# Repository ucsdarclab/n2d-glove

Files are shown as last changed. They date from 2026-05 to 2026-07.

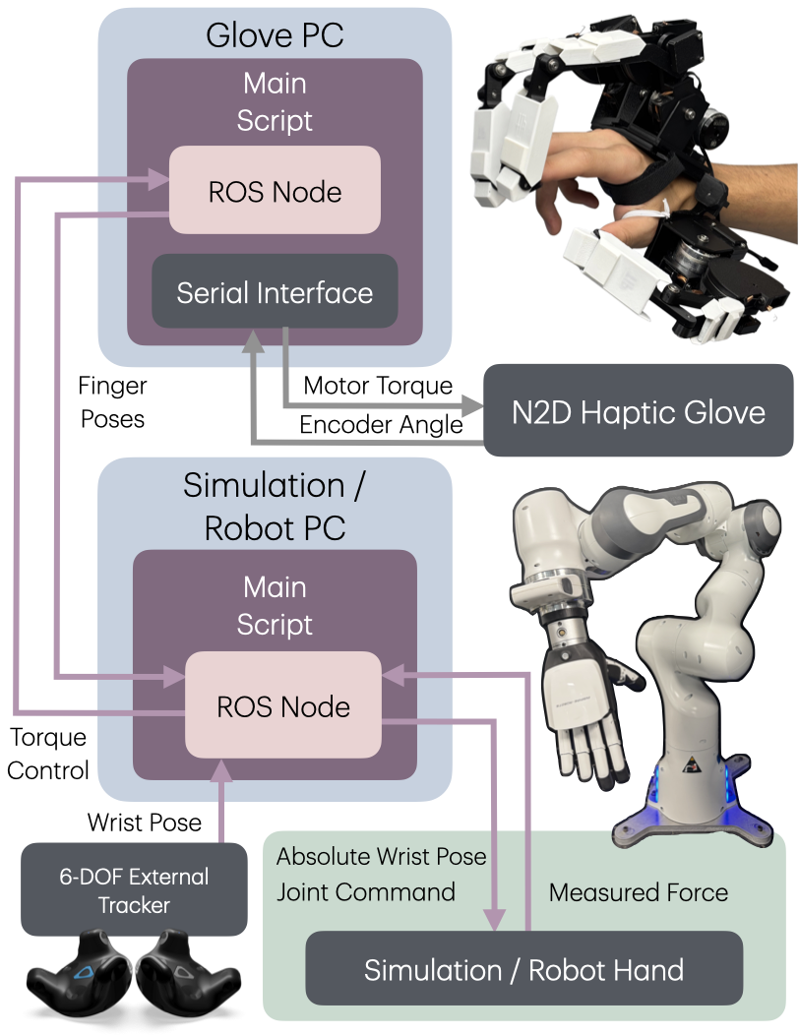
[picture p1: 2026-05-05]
website/src/assets/fig3_architecture.png

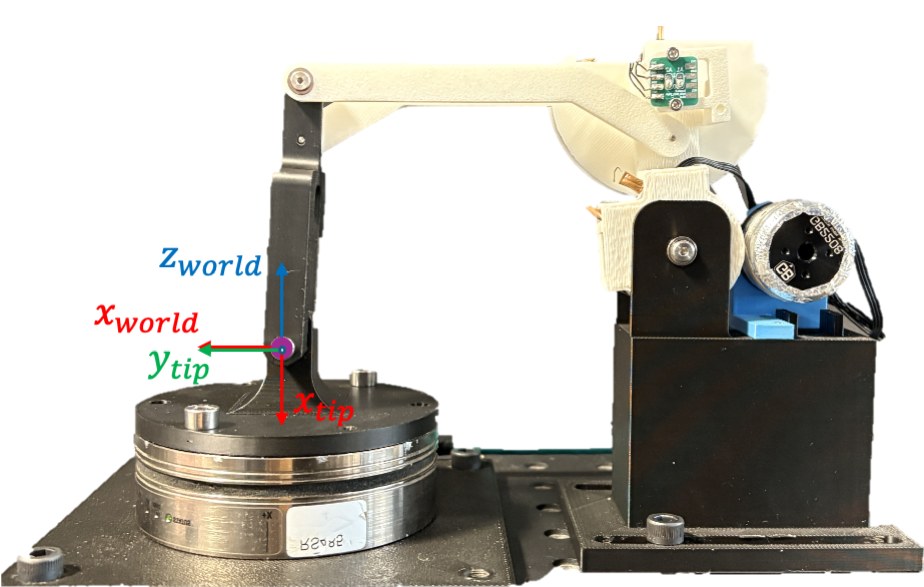
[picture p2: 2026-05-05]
website/src/assets/fig5_calibration.jpg

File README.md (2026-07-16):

# n2d-glove

- `website/` - Project Website at [ucsdarclab.github.io/n2d-glove/](https://ucsdarclab.github.io/n2d-glove/)
- `PCBs/` - PCB Files
- `STLs/` - Ready-to-print STL files for right-hand glove. All files pre-duplicated for easy printing.

## Parts List (As of 07/11/2026)

[Google Sheet](https://docs.google.com/spreadsheets/d/1Ua4gmWuUEBylOtv7NlKw2PqBZjRJq9b11pPJc5YkHVY/edit?usp=sharing)

| Part | Easy Buy Link | Link | Quantity | Unit Price | Total Price | Description |
| --- | --- | --- | --- | --- | --- | --- |
| GB2208 | No | https://store.tmotor.com/goods.php?id=447 | 6 | $25.90 | $155.40 | 2 motors per finger x 3 fingers (6 required). |
| Main PCB (CompactN2D) | No | https://github.com/ucsdarclab/n2d-glove/raw/refs/heads/main/PCBs/CompactN2D%20Gerbers.zip | 1 | $10 | $10 | Large PCB with Teensy 4.1 and 6x Driver Boards |
| Encoder PCB (ARCLab miniAS5048B) | No | https://github.com/ucsdarclab/n2d-glove/raw/refs/heads/main/PCBs/ARCLab_miniAS5048B_Gerbers.zip | 10 | $1 | $10 | Small PCB for mounting encoder. 3 per finger plus 1 thumb |
| AS5048B encoder IC (AS5048B-HTSP) | DigiKey Cart Share | https://www.digikey.com/en/products/detail/ams-osram-usa-inc/AS5048B-HTSP/3188635 | 10 | $6.46 | $64.60 | 12-bit magnetic angle encoder with programmable I2C address |
| 4-pin encoder cable | https://www.digikey.com/short/v38wvwd3 | https://www.digikey.com/en/products/detail/molex/2263921043/23571260 | 3 | $3.10 | $9.30 | One per finger |
| 4-pin encoder connector | ^ | https://www.digikey.com/en/products/detail/molex/2147210040/16115264 | 3 | $1.26 | $3.78 | One per finger |
| 100nF 0603 capacitor (CL10B104JB8NNNC) | ^ | https://www.digikey.com/en/products/detail/samsung-electro-mechanics/CL10B104JB8NNNC/3886691 | 10 | $0.04 | $0.40 | One per encoder PCB |
| 10uF 0603 capacitor (CL10A106KP8NNNC) | ^ | https://www.digikey.com/en/products/detail/samsung-electro-mechanics/CL10A106KP8NNNC/3886850 | 10 | $0.10 | $1.00 | One per encoder PCB |
| Teensy 4.1 without Ethernet (SparkFun 20359) | ^ | https://www.digikey.com/en/products/detail/sparkfun-electronics/20359/16688101 | 1 | $29.60 | $29.60 | Main PCB Microcontroller |
| 3.5mm Screw Terminal (GCT TAD05-02-1-L-G) | ^ | https://www.digikey.com/en/products/detail/gct/TAD05-02-1-L-G/26408919 | 1 | $0.41 | $0.41 | Main PCB Power Input |
| 4-conductor 28 AWG ribbon cable (Adafruit 3891) | ^ | https://www.digikey.com/en/products/detail/adafruit-industries-llc/3891/9603617 | 1 | $1.95 | $1.95 | Extra wire for connecting encoders |
| Shoulder screw 3x8mm (90318A416) | McMaster Cart Share | https://www.mcmaster.com/90318A416/ | 12 | $3.66 | $43.92 | 12 required. M2 x 0.4 threaded tip |
| Shoulder screw 4x12mm (90323A216) | https://www.mcmaster.com/order/rcvRtedOrd.aspx?ordid=4762453288527&lnktyp=txt | https://www.mcmaster.com/90323A216/ | 4 | $4.13 | $16.52 | 4 required. M3 x 0.5 tip |
| Shoulder screw 4x30mm (90323A443) | ^ | https://www.mcmaster.com/90323A443/ | 3 | $10.52 | $31.56 | 3 required, 1 per front GB2208 motor. M3 x 0.5 tip |
| Shim 1/8"ID x 3/16"OD x 0.005" (99040A305) | ^ | https://www.mcmaster.com/99040A305/ | 2 pack (25) | $14.06/pack | $28.12 | 24 required. Slips over 3mm shoulder screws. Fragile recommend extra |
| Shim 3/16"ID x 1/4"OD x 0.005" (99040A405) | ^ | https://www.mcmaster.com/99040A405/ | 1 pack (25) | $14.06/pack | $14.06 | 14 required. Slips over 4mm shoulder screws |
| M3x8 flat head screw (92125A128) | ^ | https://www.mcmaster.com/92125A128/ | 1 pack (100) | $7.08/pack | $7.08 | 18 required. For motor mounts and plate mounts |
| M3 thin hex nut, stainless (90710A030) | ^ | https://www.mcmaster.com/90710A030/ | 1 pack (100) | $13.52/pack | $13.52 | 3 required, on 4x30 bolt tip at front motor |
| M2 hex nut (90591A265) | ^ | https://www.mcmaster.com/90591A265/ | 1 pack (100) | $2.22/pack | $2.22 | 6 required, capstan wire tensioners. |
| M2 washer (93475A195) | ^ | https://www.mcmaster.com/93475A195/ | 1 pack (100) | $2.92/pack | $2.92 | 6 required, under tensioner nuts. |
| M2x20 socket head screw (91290A049) | ^ | https://www.mcmaster.com/91290A049/ | 1 pack (100) | $16.58/pack | $16.58 | 6 required, capstan wire tension screws. |
| M2.5x5 button head screw (92095A457) | ^ | https://www.mcmaster.com/92095A457/ | 1 pack (25) | $4.42/pack | $4.42 | Encoder holder screws, 2 per encoder (20 required) |
| Diametric magnet 3/16"x1/16" (5862K412) | ^ | https://www.mcmaster.com/5862K412/ | 10 | $1.33 | $13.30 | One per encoder. N52, must be diametric |
| Capstan drive wire rope 7x19 (3461T192) | ^ | https://www.mcmaster.com/3461T192/ | 1 (10 ft) | $18.37 | $18.37 | 18-8 SS extra-flexible, 0.018" dia. |
| Copper Wire Rope Stop Sleeve, 1/32" (McMaster 3926T42) | ^ | https://www.mcmaster.com/3926T42/ | 1 pack (50) | $9.47/pack | $9.47 | Crimps to terminate capstan wire |
| SimpleFOC Mini Driver Board | No | https://www.aliexpress.us/w/wholesale-simplefoc-mini.html | 6 | $5.74 | $34.44 | 6 for 6 motors |
| Heat-set insert kit M2 + M2.5 + M3 (Ktehloy 400pc) | No | https://www.amazon.com/dp/B0CLKDPN65 | 1 kit (400pc) | $14.98 | $14.98 | Encoder mounts, thumb CMC joint. etc. |
| MF63ZZ flanged bearing 3x6x2.5mm | No | https://www.amazon.com/dp/B0F4XS52R6 | 20+10 (30) | $9.49 + $8.19 | $17.68 | 24 required, ~8/finger |
| MF74ZZ flanged bearing 4x7x2.5mm | No | https://www.amazon.com/dp/B0F4XPW7YB | 1 pack (20) | $8.49/pack | $8.49 | 14 required, ~5/finger |
| 1/2in x 100ft Hook and Loop Roll | No | https://www.amazon.com/dp/B0CH8K8VWC | 1 | $7.99 | $7.99 | Velcro for palm attachment, ~1ft needed |
| Graphite Dry Lock Lubricant Powder, 4.5g | No | https://www.amazon.com/dp/B00YRZUGH6 | 1 | $5.15 | $5.15 | Lubricant for smoother abduction/adduction |
| Elastic Bracelet String, 2 Rolls (1.5mm) | No | https://www.amazon.com/dp/B0CBTRGHJN | 1 | $7.99 | $7.99 | Elastic cord for thumb attachment, ~0.5ft needed |
| Total Price |  |  |  |  | $605.22 |  |

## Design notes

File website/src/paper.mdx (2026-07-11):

---
title: "The N2D Haptic Glove"
subtitle: "A Multi-Finger Glove for 2D Directional Force Feedback for Contact-Rich Manipulation"
authors:
  - name: Yao-Ting Huang
    notes: ["†", "1"]
  - name: Jake Honma
    notes: ["†", "2"]
  - name: Omar Hernandez
    notes: ["†", "1"]
  - name: Logan Li
    notes: ["†", "3"]
  - name: Kaitlin Calimbahin
    notes: ["†", "1"]
  - name: Bryce Hackel
    notes: ["1"]
  - name: Michael C. Yip
    notes: ["1"]
    institution: Senior Member, IEEE
notes:
  - symbol: "†"
    text: " Equal contribution."
  - symbol: "1"
    text: " Electrical and Computer Engineering, University of California San Diego, La Jolla, CA 92093, USA."
  - symbol: "2"
    text: " Mechanical and Aerospace Engineering, University of California San Diego, La Jolla, CA 92093, USA."
  - symbol: "3"
    text: " Bioengineering, University of California San Diego, La Jolla, CA 92093, USA."
links:
  - name: Paper
    url: "https://arxiv.org/pdf/2606.14083"
    icon: ri:file-pdf-2-line
  - name: Code
    url: "https://github.com/ucsdarclab/n2d-glove"
    icon: ri:github-line
  - name: arXiv
    url: "https://arxiv.org/abs/2606.14083"
    icon: academicons:arxiv

theme: device
favicon: favicon.svg

description: A wearable multi-finger haptic glove that renders 2D planar directional force feedback at the fingertips for contact-rich teleoperation, VR, and imitation learning.
thumbnail: og-thumbnail.jpg
---

import Video from "./components/Video.astro";
import HighlightedSection from "./components/HighlightedSection.astro";
import Figure from "./components/Figure.astro";
import Picture from "./components/Picture.astro";
import TwoColumns from "./components/TwoColumns.astro";
import Wide from "./components/Wide.astro";

import fig1Hero from "./assets/fig1_hero.jpg";
import fig2Linkage from "./assets/fig2_linkage.png";
import fig3Architecture from "./assets/fig3_architecture.png";
import fig4Kinematics from "./assets/fig4_kinematics.png";
import fig5Calibration from "./assets/fig5_calibration.jpg";
import fig5Tracking from "./assets/fig5_tracking.png";
import fig6Workspace from "./assets/fig6_workspace.jpg";
import fig7Franka from "./assets/fig7_franka.jpg";
import fig8Boxplots from "./assets/fig8_boxplots.png";
import fig9Tlx from "./assets/fig9_tlx.png";

<Figure>
  <Picture slot="figure" src={fig1Hero} alt="The N2D Haptic Glove worn on a hand" />
  <Fragment slot="caption">**The N2D Haptic Glove** — the first multi-fingered glove design that offers 2D force feedback along the axial direction of multiple fingers, enabling probing, gentle grasping, and slip detection.</Fragment>
</Figure>

<HighlightedSection>

## Abstract

Humans rely on directional fingertip forces to probe and regulate contact during manipulation, yet most wearable haptic gloves render only vibration or single-axis force, leaving force direction ambiguous. Without directional cues, users must infer contact force from vision alone, often leading to over-pressing, inconsistent control, and reduced precision in robotic teleoperation. We present the **N2D Haptic Glove**, a multi-finger wearable device that renders planar flexion–extension fingertip forces using capstan-drive transmissions for high-transparency force feedback. Through benchtop validations and a user study involving haptic teleoperation of a robotic arm and hand, we demonstrate that compared to visual-only and single-axis baselines, planar fingertip feedback significantly reduces contact force error during precise manipulation, improves trial-to-trial consistency, and enhances overall user experience in axial probing tasks.

</HighlightedSection>

## Contributions

1. The **first** multi-fingered haptic glove capable of delivering planar force feedback to the fingertip.
2. A mechanical design that achieves high transparency through low-friction, zero-backlash transmissions for clean, accurate haptic rendering.
3. Validation of 2D planar directional feedback ability with benchtop testing.
4. A teleoperation user study demonstrating the benefits of N2D's directional haptics over no-haptic and 1D-haptic baselines.

## Hardware Design

The N2D Haptic Glove is designed to preserve the natural biomechanical DOFs of the hand. The MCP joint is treated as a saddle joint allowing flexion–extension and adduction–abduction; PIP and DIP joints are modeled as revolute joints constrained to flexion–extension. The thumb additionally performs opposition at the TMC joint. The thumb, index, and middle fingers — central to most grasping and probing tasks — are actuated.

The device consists of three modular finger subsystems mounted along a structural backbone. Each subsystem uses a crossed four-bar linkage with an additional link to permit full flexion–extension while enabling 2D planar force feedback. Planar fingertip forces are generated by actuating the proximal links via capstan cable drives. Each linkage is mounted on a passive rotary joint for finger abduction–adduction, with the thumb having an additional passive joint for TMC opposition.

All active DOFs are driven by **GB2208 gimbal motors** through capstan transmissions, avoiding geared transmissions that introduce backlash, friction, and damping. Actuators are mechanically grounded at the base of the linkage, preventing motor masses from rotating about the finger joints. The total glove weighs **562 g** (battery off-hand).

<Figure>
  <Picture slot="figure" src={fig2Linkage} alt="Deconstructed view of the N2D Haptic Glove finger linkage" />
  <Fragment slot="caption">Deconstructed view of the N2D Haptic Glove showing finger linkage joint layout and its correspondence to hand anatomy.</Fragment>
</Figure>

### Comparison to Existing Fingertip-Feedback Systems

| System | Multi-DOF Forces | Kinesthetic | Multi-Digit |
| :--- | :---: | :---: | :---: |
| SenseGlove R1 | ✗ | ✓ | ✓ |
| HaptGlove | ✗ | ✓ | ✓ |
| DOGlove | ✗ | ✓ | ✓ |
| NURing | ✓ | ✓ | ✗ |
| Fluid Reality | ✗ | ✗ | ✓ |
| AirPush | ✓ | ✗ | ✗ |
| **N2D Glove (ours)** | **✓** | **✓** | **✓** |

## System Architecture

The Glove PC computes finger poses from encoder data and sends joint commands to the Simulation/Robot PC via ROS. Each motor–encoder pair interfaces with a Teensy 4.1 microcontroller running field-oriented control in torque mode at **1 kHz**, while higher-level torque commands stream from the Glove PC at **10 Hz** over a serial connection. An external **VIVE Tracker 3.0** provides absolute wrist pose, fused with fingertip pose estimates. Sensed interaction forces are returned through ROS and mapped to motor commands, closing the bilateral control loop.

<Figure>
  <Picture slot="figure" src={fig3Architecture} alt="N2D Haptic Glove system architecture diagram" />
  <Fragment slot="caption">System architecture. The Glove PC computes finger poses from encoder data and sends joint commands to the Simulation/Robot PC via ROS. Sensed interaction forces are returned and mapped to motor commands.</Fragment>
</Figure>

## Kinematic Modeling

<Figure>
  <Picture slot="figure" src={fig4Kinematics} alt="Single finger linkage with three DOFs and labeled coordinate frames" />
  <Fragment slot="caption">Kinematic analysis of a single finger linkage with three DOFs defined by $q_0, q_1, q_2$ ($q_3$ being a driven joint).</Fragment>
</Figure>

Each finger is modeled as a rigid linkage with three revolute joints $q_{f,0}, q_{f,1}, q_{f,2}$ and link lengths $a_{f,0}, a_{f,1}, a_{f,2}, a_{f,3}$. The driven angle $q_{f,3}$ is solved via the cosine law:

$$
CD = \ell_4 = \sqrt{a_2^2 + \ell_5^2 + 2 a_2 \ell_5 \cos q_{f,2}}
$$

Directional haptics are then rendered by mapping Cartesian forces in the world frame, $\mathbf{f}^w_f \in \mathbb{R}^3$, to joint torques $\boldsymbol{\tau}_f \in \mathbb{R}^2$ via the **Jacobian transpose**:

$$
\boldsymbol{\tau}_f = \mathbf{J}^w_f(\mathbf{q}_f)^\top \mathbf{f}^w_f
$$

Because each finger has only two active DOF, the achievable Cartesian forces lie in a configuration-dependent 2D subspace of $\mathbb{R}^3$. The Jacobian-transpose mapping naturally projects any commanded force onto this subspace; the un-actuated direction (finger abduction/adduction) is not reflected.

## Validation Experiments

A voltage–torque mapping is identified per joint via a quasi-static calibration. Circular planar force trajectories were commanded and measured with an ATI Axia80 3-DOF sensor.

- **RMSE_x = 0.032 N**
- **RMSE_z = 0.014 N**
- **RMSE_|e| = 0.034 N**, **RMSE_θ = 2.81°**

The fingertip Jacobian is well-conditioned with $\kappa(\mathbf{J}^w_f) \approx 2.93$, and the manipulability $w(\mathbf{q}_f) \geq 0.82$ over **58%** of sampled configurations — confirming that directional forces can be rendered cleanly across most reachable hand postures.

<Figure>
  <Picture slot="figure" src={fig5Calibration} alt="Force calibration setup with finger linkage mounted on an ATI force sensor" />
  <Fragment slot="caption">Force calibration setup showing the world coordinate frame ($x_{\text{world}}$, $z_{\text{world}}$) and the tip coordinate frame ($x_{\text{tip}}$, $y_{\text{tip}}$).</Fragment>
</Figure>

<Figure>
  <Picture slot="figure" src={fig5Tracking} alt="Force tracking results: commanded vs. measured along x and z axes, and in the x z plane" />
  <Fragment slot="caption">Individual commanded and measured force components along the x and z axes (left), and measured forces in the x–z plane compared to the commanded circular trajectory (right). RMSE: $0.032$ N (x), $0.014$ N (z), $0.034$ N (magnitude), $2.81°$ (angle).</Fragment>
</Figure>

<Figure>
  <Picture slot="figure" src={fig6Workspace} alt="Workspace range-of-motion scatter for small and large hands" />
  <Fragment slot="caption">Workspace range of motion for a small and large hand. The overlaid manipulability indicates configuration-dependent directional force capability, showing well-conditioned force generation throughout typical operating regions.</Fragment>
</Figure>

## Teleoperation User Study

Sixteen participants teleoperated a **Franka Emika Panda** arm with an **Inspire RH56DFTP** dexterous hand to press a digital scale toward target weights of 50 g and 100 g, under three feedback modes: **no haptics**, **1D haptics**, and **full 2D haptics**. Two contact orientations were tested: axial probing (fingertip contact) and transverse probing (finger pad contact).

<Figure>
  <Picture slot="figure" src={fig7Franka} alt="Franka arm and Inspire hand scale-pressing teleoperation setup" />
  <Fragment slot="caption">Teleoperation setup: a Franka arm with an Inspire dexterous hand presses a digital scale toward a target weight under three feedback conditions.</Fragment>
</Figure>

### Results

In **axial probing**, median absolute error decreased progressively from no-haptics → 1D → 2D feedback. At the 100 g target, 2D feedback significantly outperformed both 1D ($p = 0.032$) and no-feedback ($p = 1.43 \times 10^{-5}$) conditions, demonstrating that 2D directional feedback enhances force regulation where single-DOF resistive feedback is insufficient.

| Condition | Mode | Median Abs. Err. (g) | $p$ vs. Vis | $p$ vs. 1D |
| :--- | :--- | :---: | :---: | :---: |
| Axial 50 g | Visual | 37.68 | — | $2.53\!\times\!10^{-4}$ |
| Axial 50 g | 1D | 30.80 | $2.53\!\times\!10^{-4}$ | — |
| Axial 50 g | **2D** | **24.99** | $2.56\!\times\!10^{-6}$ | 0.276 |
| Axial 100 g | Visual | 50.25 | — | 0.032 |
| Axial 100 g | 1D | 34.73 | 0.032 | — |
| Axial 100 g | **2D** | **21.20** | $1.43\!\times\!10^{-5}$ | **0.032** |
| Transverse 50 g | **2D** | **27.85** | $5.07\!\times\!10^{-4}$ | 0.876 |
| Transverse 100 g | **2D** | **46.52** | 0.0315 | 0.985 |

<Figure>
  <Picture slot="figure" src={fig8Boxplots} alt="Boxplots of absolute error for 50 g and 100 g target weights across feedback modalities" />
  <Fragment slot="caption">Boxplots of absolute error (g) for target weights of 50 g and 100 g. In axial probing, median error decreases progressively from visual-only to 1D to 2D feedback.</Fragment>
</Figure>

NASA-TLX surveys show that 2D haptic feedback significantly **reduces cognitive load** and increases **perceived feedback quality** for both axial and transverse probing.

<Figure>
  <Picture slot="figure" src={fig9Tlx} alt="NASA-TLX survey results across feedback modalities" />
  <Fragment slot="caption">Individual NASA-TLX survey results for axial and transverse probing, demonstrating that multi-directional haptic feedback significantly reduces cognitive load while improving overall performance for participants.</Fragment>
</Figure>

## Conclusion

Directional fingertip haptics are essential for realistic physical interaction in teleoperation. The N2D Haptic Glove demonstrates that multi-directional 2D feedback is both feasible and beneficial for contact-rich tasks, particularly those involving axial probing — pushing small buttons, palpation, peg-in-hole insertion, and fingertip-based search in confined environments. The glove provides a foundation for next-generation wearable haptic interfaces supporting more natural and effective human–robot interaction across teleoperation, immersive VR simulation, and imitation learning.

## BibTeX

```bibtex
@misc{n2dglove2026,
  author = "{Authors Redacted}",
  title  = "The N2D Haptic Glove: A Multi-Finger Glove for 2D Directional
            Force Feedback for Contact-Rich Manipulation",
  year   = "2026",
}
```

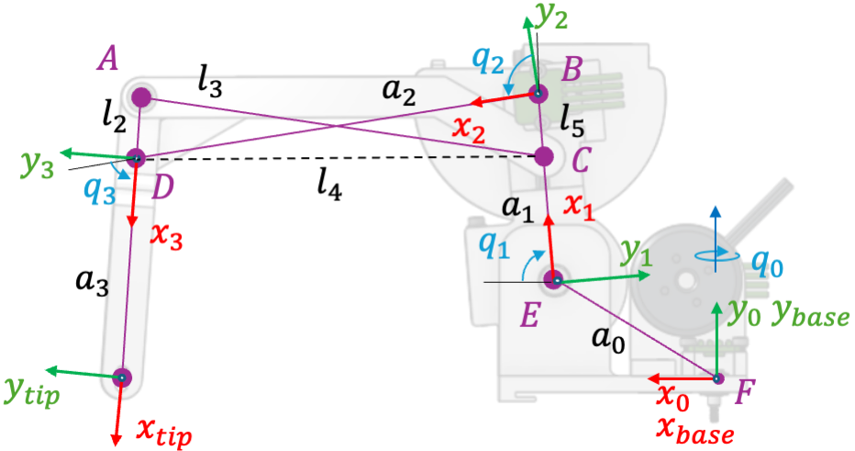
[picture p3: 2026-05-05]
website/src/assets/fig4_kinematics.png

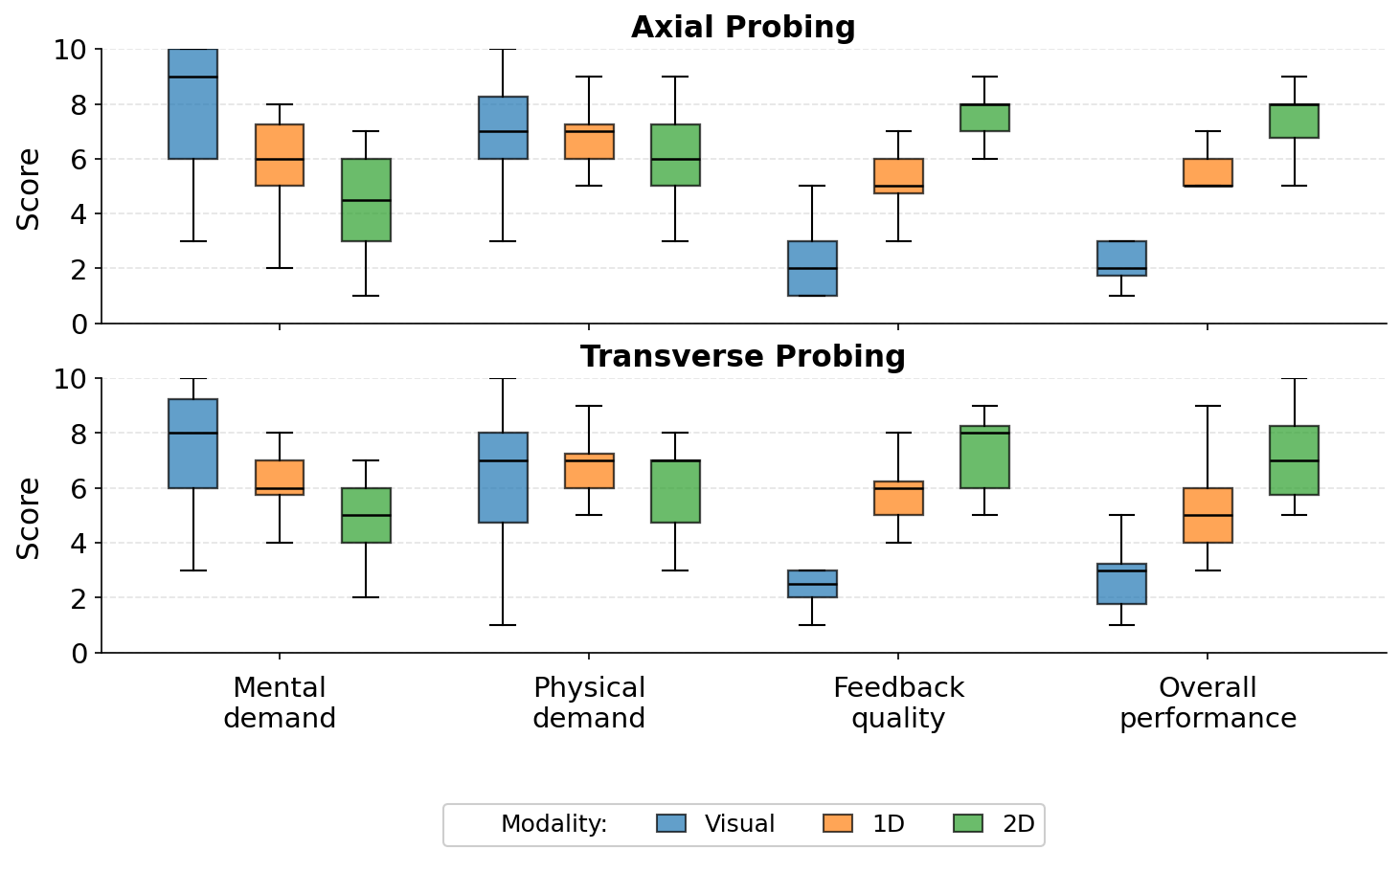
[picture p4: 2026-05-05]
website/src/assets/fig9_tlx.png

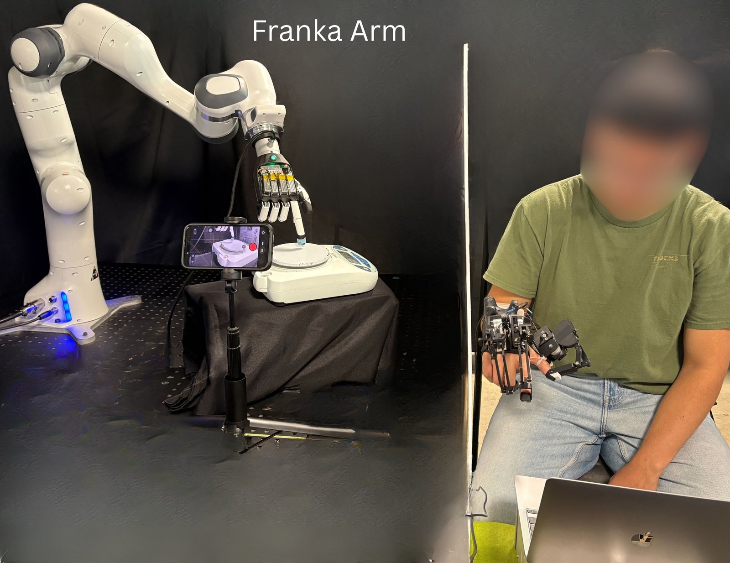
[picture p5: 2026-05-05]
website/src/assets/fig7_franka.jpg

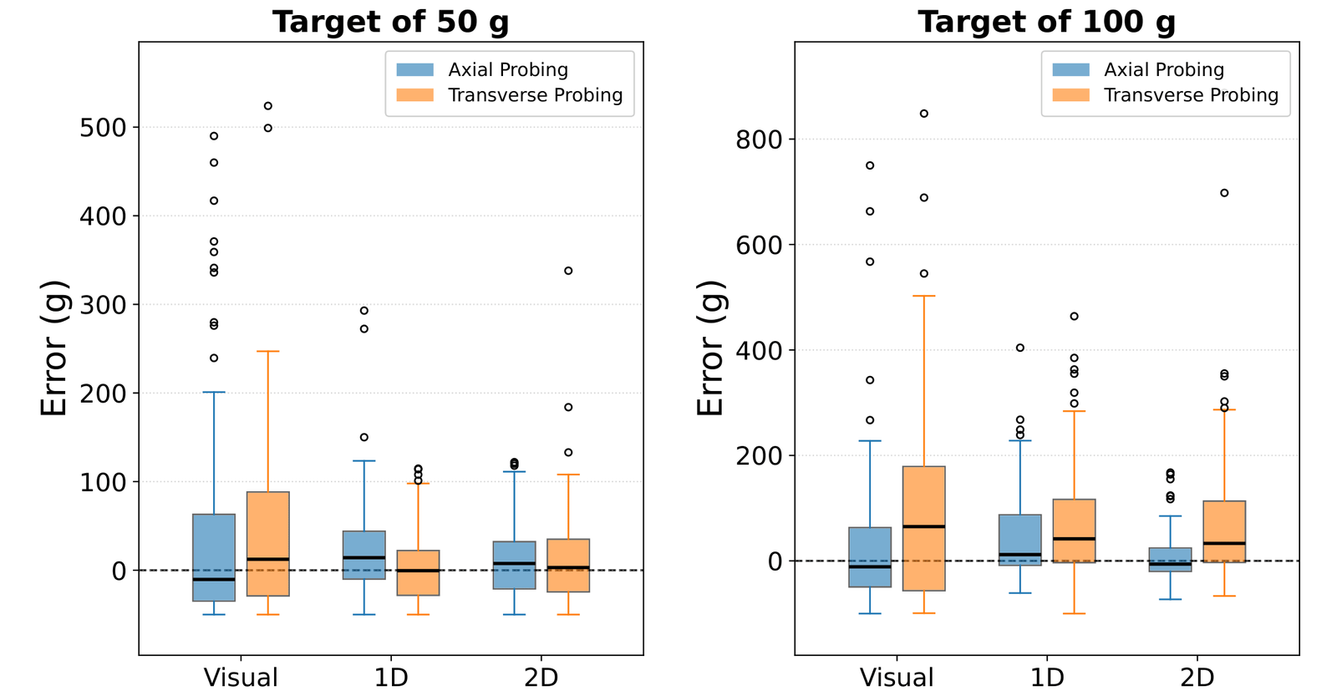
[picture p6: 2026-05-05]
website/src/assets/fig8_boxplots.png

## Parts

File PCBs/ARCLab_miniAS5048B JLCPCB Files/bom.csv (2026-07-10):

Designator | Footprint | Quantity | Value | LCSC Part #
A1, A2 | SolderJumper-3_P1.3mm_Open_RoundedPad1.0x1.5mm | 2 | SolderJumper_3_Open
C1 | 0603 | 1 | 100n | CL10B104KB8NNNC
C2 | 0603 | 1 | 10u | CL10A106MP8NNNC
J1, J2 | 4Pin Wire SolderPad | 2 | Conn_01x04_Pin
U1 | SOP65P640X120-14N | 1 | AS5048B-HTSP-500 | C2655184

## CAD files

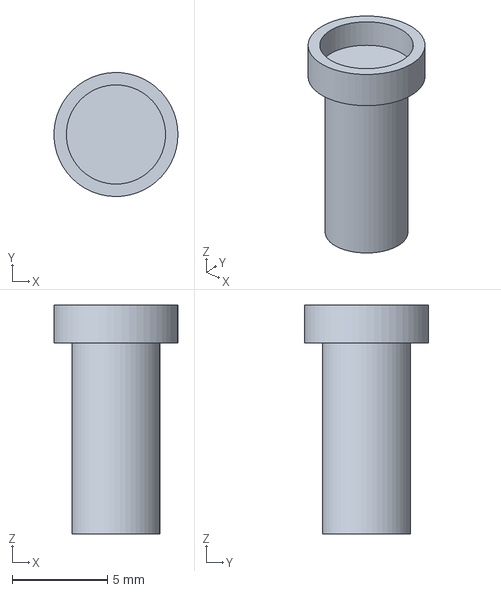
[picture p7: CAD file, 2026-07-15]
STEPs/3 Finger Assembly - Magnet Shaft.step
6.49 x 6.50 x 12.0 mm

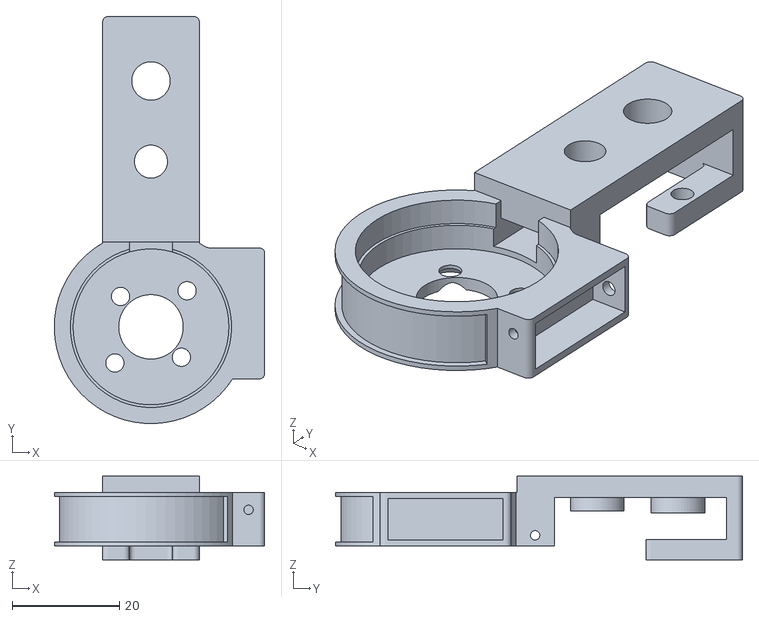
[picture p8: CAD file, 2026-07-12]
STLs/3 Finger Assembly - Capstan Drive Proximal Link Thumb and Pointer (copy 2).stl
39.2 x 75.7 x 15.5

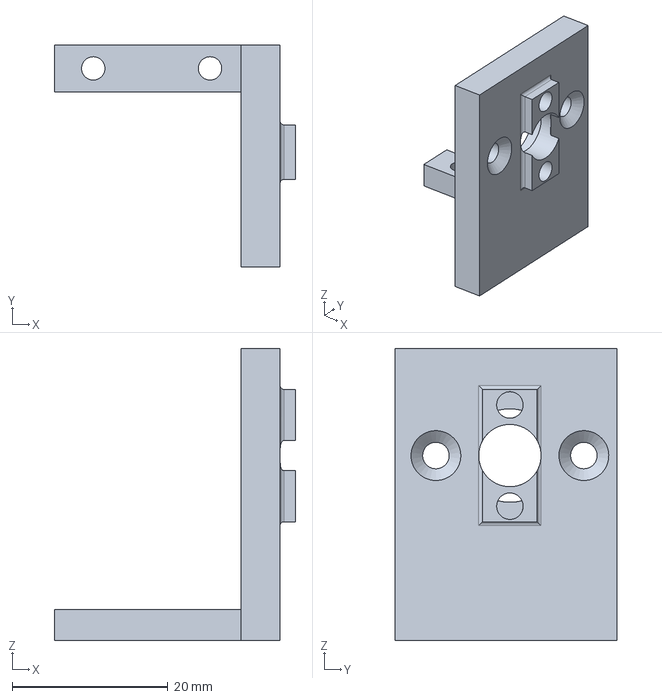
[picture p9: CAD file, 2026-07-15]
STEPs/3 Finger Assembly - Back Motor Mount Thumb.step
31.0 x 28.5 x 37.5 mm

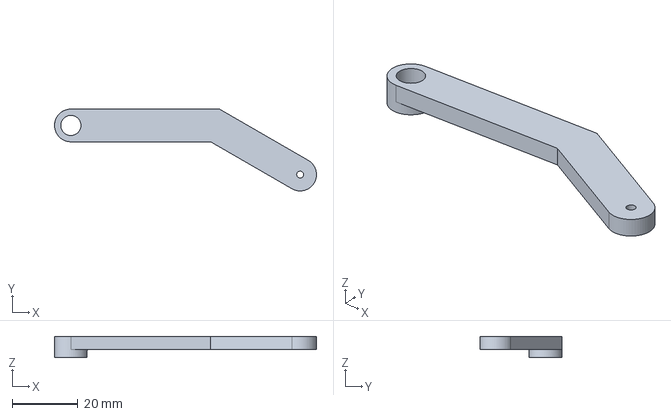
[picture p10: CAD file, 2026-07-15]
STEPs/3 Finger Assembly - Free Moving Top Bar Thumb.step
80.0 x 25.0 x 6.50 mm

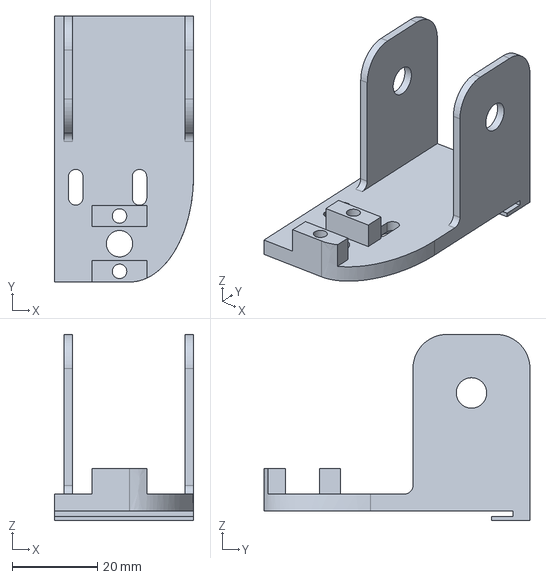
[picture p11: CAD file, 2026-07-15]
STEPs/3 Finger Assembly - Base Plate Pointer Finger.step
32.7 x 62.5 x 43.8 mm

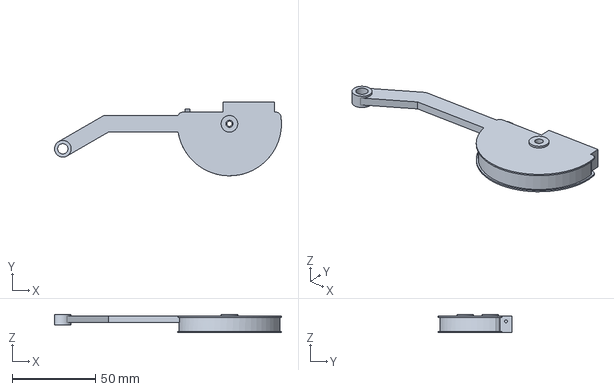
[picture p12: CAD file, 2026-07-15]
STEPs/3 Finger Assembly - Capstan Drive Top Bar Pointer Finger.step
136.2 x 44.2 x 11.0 mm

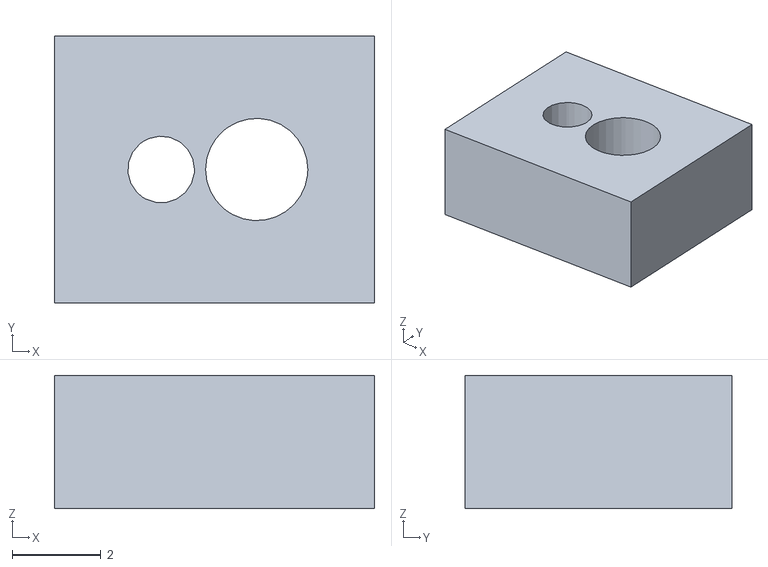
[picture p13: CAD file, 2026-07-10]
STLs/3 Finger Assembly - Capstan Drive Block Top Bar (copy 2).stl
7.20 x 6.00 x 3.00

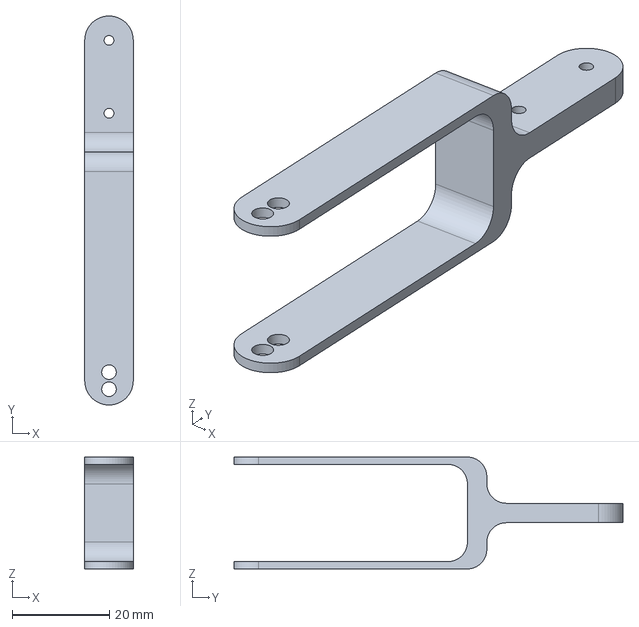
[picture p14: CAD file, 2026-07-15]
STEPs/3 Finger Assembly - Pointer Finger and Thumb Fingertip Link.step
10.0 x 80.0 x 23.0 mm

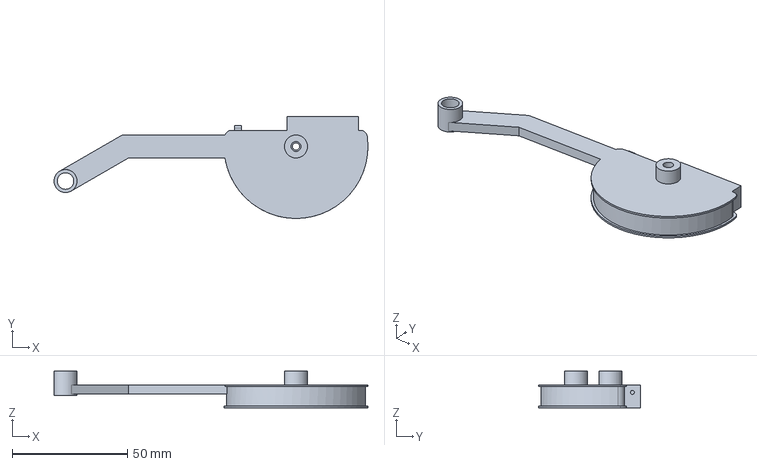
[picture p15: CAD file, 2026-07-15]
STEPs/3 Finger Assembly - Capstan Drive Top Bar Middle Finger.step
136.2 x 44.2 x 16.0 mm

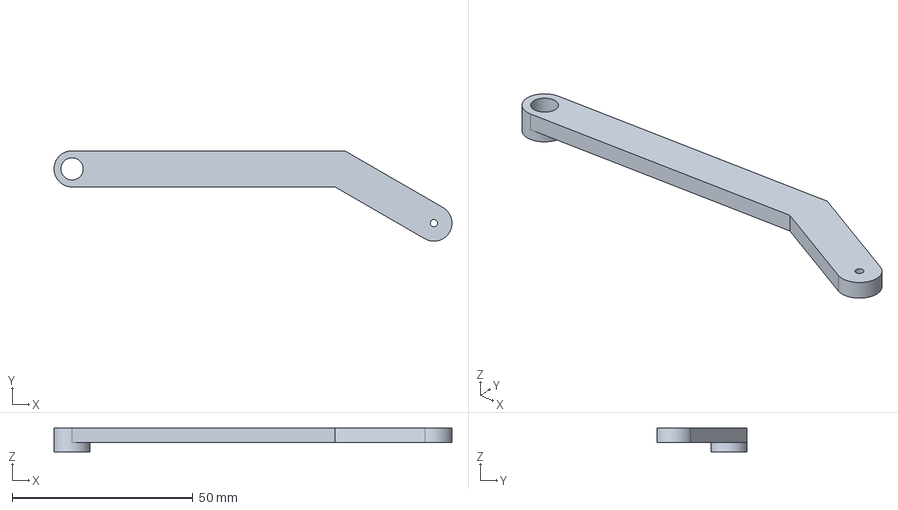
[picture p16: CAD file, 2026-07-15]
STEPs/3 Finger Assembly - Free Moving Top Bar Pointer Finger.step
110.0 x 25.0 x 6.50 mm

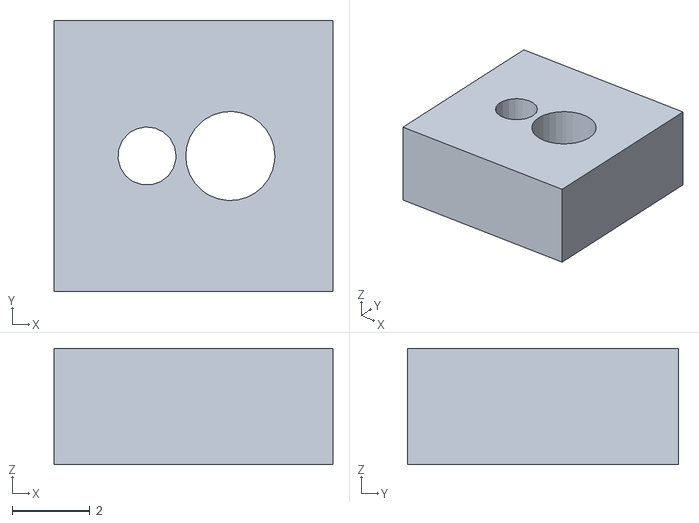
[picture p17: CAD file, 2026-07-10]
STLs/3 Finger Assembly - Capstan Drive Block Proximal Link (copy 3).stl
7.20 x 7.00 x 3.00

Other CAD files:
STLs/3 Finger Assembly - Magnet Shaft (copy 3).stl
STLs/3 Finger Assembly - Pointer Finger and Thumb Fingertip Link (copy 2).stl
STEPs/3 Finger Assembly - Back Motor Mount Pointer Finger.step
STLs/3 Finger Assembly - Magnet Shaft (copy 2).stl
STEPs/3 Finger Assembly - Back Motor Mount Middle Finger.step
STEPs/3 Finger Assembly - Base Plate Middle Finger.step
STEPs/3 Finger Assembly - Base Plate Thumb.step
STEPs/3 Finger Assembly - Capstan Drive Block Proximal Link.step
STEPs/3 Finger Assembly - Capstan Drive Block Top Bar.step
STEPs/3 Finger Assembly - Capstan Drive Proximal Link Middle Finger.step
STEPs/3 Finger Assembly - Capstan Drive Proximal Link Pointer Finger.step
STEPs/3 Finger Assembly - Capstan Drive Top Bar Thumb.step
STEPs/3 Finger Assembly - Free Moving Top Bar Middle Finger.step
STEPs/3 Finger Assembly - Hand Base.step
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

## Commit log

2026-07-10 Added PCBs
    [bom.csv, designators.csv, positions.csv]
2026-07-10 Added STLs
    [3 Finger Assembly - Back Motor Mount Middle Finger.stl, 3 Finger Assembly - Back Motor Mount Pointer Finger.stl, 3 Finger Assembly - Back Motor Mount Thumb.stl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]
2026-07-11 Improved parts
    [3 Finger Assembly - Back Motor Mount Middle Finger.stl, 3 Finger Assembly - Back Motor Mount Pointer Finger.stl, 3 Finger Assembly - Back Motor Mount Thumb.stl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]
2026-07-12 Swap in updated capstan drive proximal links
    [3 Finger Assembly - Capstan Drive Proximal Link Middle Finger.stl, 3 Finger Assembly - Capstan Drive Proximal Link Pointer Finger.stl, 3 Finger Assembly - Caps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]
2026-07-14 Resize for heat sets
    [3 Finger Assembly - Back Motor Mount Middle Finger.stl, 3 Finger Assembly - Back Motor Mount Pointer Finger.stl, 3 Finger Assembly - Back Motor Mount Thumb.stl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]
2026-07-14 Update screw terminal to 3.5mm pitch and add ribbon wire
2026-07-15 Use new capstan link for all fingers
    [3 Finger Assembly - Capstan Drive Proximal Link Pointer Finger (copy 2).stl, 3 Finger Assembly - Capstan Drive Proximal Link Pointer Finger.stl]
2026-07-15 Add step files
    [3 Finger Assembly - Back Motor Mount Middle Finger.step, 3 Finger Assembly - Back Motor Mount Pointer Finger.step, 3 Finger Assembly - Back Motor Mount Thumb.s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]
2026-07-16 Switch encoder holder screws to M2.5x5 button head
